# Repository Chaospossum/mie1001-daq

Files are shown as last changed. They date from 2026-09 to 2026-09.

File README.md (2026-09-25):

# MIE1001 Team 5&4 — data acquisition for the portable quadrupole mass spectrometer

Foundation of Imaging Engineering (MIE1001), Maastricht University, 2026.
Team 5 owns the data chain: detector signal → preamp → ADC → Arduino UNO → laptop, plus the DAC that
sends the mass command to the Extrel 150-QC quadrupole controller.

```
Faraday cup ─► preamp (LMP7721, 100 MΩ) ─► ADS1115 16-bit ADC ─I²C─► Arduino UNO ─USB─► laptop
                                               MCP4725 12-bit DAC ◄─I²C─┘ ─► mass command (0-5 V now; Extrel wants 0-10 V)
```

## Contents

| Folder | What |
|---|---|
| `firmware/` | Arduino sketches (open in the Arduino IDE; board: Arduino Uno) |
| `hardware/mie1001_daq_simple/` | **Simple shield, rev E**: plug-in ADS1115 + MCP4725 breakouts, screw terminals, and the Faraday-cup preamp. Ordered from Digi-Key and hand-soldered. See its README |
| `hardware/mie1001_daq_board/` | **Full shield, rev E**: everything soldered (ADS1115, MCP4725, preamp), BNC input, CEM/Faraday ranges |
| `hardware/enclosure/` | First idea for a 3D-printed enclosure (transparent PETG, OpenSCAD source, STLs, renders). Not printed, not a team decision yet |
| `wokwi/` | Wokwi simulation of the whole loop: Uno → MCP4725 → quadrupole stand-in → ADS1115, with custom chips written in C and a PEG1000 test spectrum |
| `data/` | Real measurements (`2026-09-20_selftest/`: first self-tests of the ADS1115 and MCP4725 on the Uno, with plots) and clearly labelled simulations (`simulations/`) |

### Firmware

| Sketch | Tests | For | Serial |
|---|---|---|---|
| `DAQ_shield_scan` | **Mass scan**: DAC code sweep on QPS OUT, preamp current (A1−A3) with 50 Hz window averaging, A2 command read-back (JP1), zero/offset, trigger on D8, self-check (`i`) | **shield** (rev E) | 115200 |
| `DAQ_loopback_test` | DAC → ADC loopback (wire QPS OUT to SIGNAL IN) | **shield** | 115200 |
| `DAQ_mini_chain` | Chain: DAC → UNO A0 → PWM D9 → RC filter → ADS1115. Assumes ADS A1 = DAC; on the shield A1 is PRE_OUT | **breadboard only** | 115200 |
| `ADS1115_selftest` | ADS1115 alone: reads the UNO's 3.3 V, GND and 5 V pins | breadboard | 9600 |
| `MCP4725_standalone_test` | MCP4725 alone, read back on the UNO's A0; scans the I²C bus if not found | breadboard | 9600 |
| `MCP4725_sine_scope` | MCP4725 sine wave, sent vs. read on the Serial Plotter | breadboard | 115200 |
| `SparkFun_MCP4725_waveform` | SparkFun's 512-point sine example (J. Bartlett, 2014, beerware). Its A2/A3 power trick is for a bare breakout on the UNO header, not the shield | breadboard (shield: drop the A2/A3 lines) | — |
| `ioannis_DAC_3V` | Ioannis's sketch: holds the MCP4725 (0x60) at 3 V. Now measures the real 5 V rail first (internal bandgap), since a fixed code 2457 gave ~2.9 V on USB | either | 115200 |
| `PwmGenerator` | Two-channel PWM generator on pins 9/10 (bench tool, not DAQ) | bench | 115200 |

Libraries: Adafruit ADS1X15, Adafruit MCP4725. I²C addresses: ADS1115 0x48, MCP4725 0x60.

### Hardware

Both boards are **generated by Python** (`generate_schematic.py`, `generate_pcb.py`); `./build.sh` rebuilds the
KiCad files, runs ERC, DRC (with schematic parity) and the preamp guard check, and writes the fab files in
`fab/` (gerbers, Digi-Key BOM; the JLCPCB files are optional leftovers). Edits made in the KiCad GUI are overwritten by the next build. Needs KiCad 10 (flatpak `org.kicad.KiCad`).
The simple board's PCB script reuses the router in `../mie1001_daq_board/`, so keep both folders side by side.

## Status (2026-09-25)

- Firmware: all sketches compile for the UNO. The self-tests pass on the real Uno (see `data/`);
  `DAQ_shield_scan` is untested until the shield is soldered.
- Simple shield rev E: fixes from an independent design review (closed guard ring under the LMP7721, mask-free
  guard, 100k/100k VREF divider, A4/A5 wired, JP1 mass-command read-back). ERC, DRC and guard check clean.
  Not yet ordered. Everything is ordered from Digi-Key and soldered by hand. Do a 1:1 paper print check on a real UNO first.
- Open: the Extrel 150-QC mass command is 0-10 V (a x2 stage with its own supply is still needed) and its
  volts-per-amu scaling is unconfirmed.

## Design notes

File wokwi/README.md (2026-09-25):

# MIE1001 — Team 5 acquisition simulation (Wokwi)

Full acquisition loop simulated in Wokwi:

    Arduino Uno --I2C--> MCP4725 (0x60) --analog--> quad --analog--> ADS1115 (0x48) --I2C--> Arduino Uno

The Uno sets a mass command on the DAC, the quad chip returns the ion
signal at that mass, the ADC reads it back. Sweeping the DAC produces a
mass spectrum.

## Files

| File | What it is |
|---|---|
| `sketch.ino` | Scan program: sweeps the DAC, reads the ADC, prints CSV |
| `diagram.json` | Wiring |
| `libraries.txt` | Adafruit ADS1X15 |
| `mcp4725.chip.c/.json` | 12-bit DAC, I2C 0x60 (Team 4's block) |
| `quad.chip.c/.json` | Quadrupole + detector model |
| `ads1115.chip.c/.json` | 16-bit ADC, I2C 0x48 (Team 5's block) |
| `signal.chip.c/.json` | Standalone free-running signal source (ADC test only) |

## Wiring

I2C bus (shared): Uno A4 = SDA, A5 = SCL. MCP4725 at 0x60, ADS1115 at 0x48.
Power: 5V and GND to both breakouts.
Analog path: MCP4725 OUT -> quad IN, quad OUT -> ADS1115 A0.

## Simulated sample

PEG1000. Peaks every 44 Da (ethylene oxide repeat) under a Gaussian
envelope centred near m/z 1010. Peak n sits at:

    m/z = 44n + 41        n = 10 .. 35

Mass command mapping in `quad.chip.c`: 0-5 V spans 0-2000 m/z, so

    DAC value = (m/z) / 2000 * 4095

## Calibration exercise

1. Run the scan, capture the CSV from the serial monitor.
2. Find peak positions in DAC counts.
3. Assign each to its known m/z using the 44 Da spacing.
4. Least-squares fit m/z = a * DAC + b.
5. Check residuals -- they should be flat, not curved.

## Parameters worth changing

`sketch.ino`
- `DWELL_MS` -- settling time per step. Set to 0 and watch peaks distort.
- `SCAN_STEP` -- 1 for full resolution, 2+ for a faster sweep.
- `AVERAGES` -- reads averaged per step; trades speed for noise.
- `ads.setGain()` -- GAIN_ONE is +/-4.096 V. Higher gain resolves more but clips sooner.

`quad.chip.c`
- `PEAK_SIGMA` -- peak width, i.e. resolution.
- `NOISE` -- baseline noise amplitude.
- `MZ_MAX` -- mass range spanned by the 0-5 V command.

## Limitations

The quad chip is a lookup, not physics. Real quadrupoles have
mass-dependent transmission, resolution set by the DC/RF ratio, and
non-Gaussian peak shapes. This is enough to develop and validate
acquisition software, not to predict instrument performance.

## Notes

- The custom chips (`*.chip.c`) were generated with AI (Claude) and checked by us; see the AI declaration in the report.
- `ADS1115_INPUT/` is a smaller first test: the ADS1115 alone with a signal source.
- To run: create a new Arduino Uno project on wokwi.com and upload these files (the chips need the "custom chip" feature).
- Files recovered from a local backup on 25 September 2026 (originally made 3 September).

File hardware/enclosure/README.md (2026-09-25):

# MIE1001 Team 5 DAQ enclosure

A two-part, support-free enclosure in **transparent (recycled) PETG** for the Arduino UNO R3 (SMD CH340
clone) with the `mie1001_daq_simple` shield (rev D/E) stacked on it. You can see the UNO's LEDs (ON, L, TX,
RX) through the side walls, in the 11 mm gap between the UNO and the shield, and you can see the shield and
both breakouts through the lid.

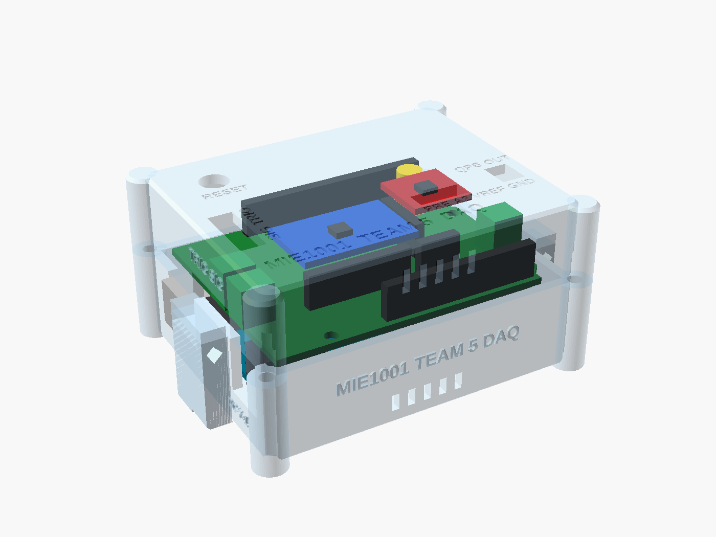
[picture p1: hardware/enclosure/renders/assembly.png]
assembled


| | |
|---|---|
| Outside (walls) | 77.4 × 61.1 × 41.5 mm (lid top 41.5 mm above the table) |
| Outside (incl. corner posts, cable-tie blocks) | 89.4 × 68.3 mm |
| Base / lid as printed | 89.4 × 68.3 × 24.7 mm / 84.6 × 68.3 × 19.5 mm |
| Filament, time (PrusaSlicer 2.9.6, 0.2 mm, 100 %) | base 37.5 g, 5 h 08 · lid 30.2 g, 4 h 02 · **total ≈ 68 g, 9 h 10** |

## Files

| Path | What |
|---|---|
| `scad/daq_enclosure.scad` | **The design.** All dimensions are parameters at the top of the file. `part = "assembly" / "exploded" / "base" / "lid" / "lid_print" / "spacer"` |
| `scad/pcb_positions.scad` | Connector positions, **generated** from the shield's `.kicad_pcb`. Don't edit it by hand |
| `stl/daq_base.stl` | Base tray, printing orientation (floor on the bed) |
| `stl/daq_lid.stl` | Lid, already flipped for printing (top face on the bed) |
| `stl/daq_spacer_x2.stl` | 2 spacers (Ø5.6 × 10.8 mm) between the UNO and the shield at holes H2/H3 |
| `print/petg_clear_0.2mm.ini` | PrusaSlicer settings (print + filament; the printer part is generic) |
| `renders/*.png` | assembly, assembly_back, exploded, boards_only, base, base_left, lid_top, lid_print |
| `build/fit_table.md` | Clearance table (generated by `tools/fit_check.py`) |
| `tools/dump_pcb.py`, `tools/make_positions.py` | KiCad board → JSON → `pcb_positions.scad`. They only read the board, from a snapshot copy |
| `build.sh` | Rebuilds everything: `./build.sh` (or `--no-pcb`, `--no-slice`) |

Tools: the OpenSCAD 2026.09.23 AppImage from files.openscad.org is in `~/Applications`. To edit, open the
`.scad` in OpenSCAD, change a parameter, press F5 (preview) or F6 (render), then **File › Export › STL**. Or run
`./build.sh`. PrusaSlicer is the flatpak `com.prusa3d.PrusaSlicer`. Its CLI runs without a display.

## How it goes together

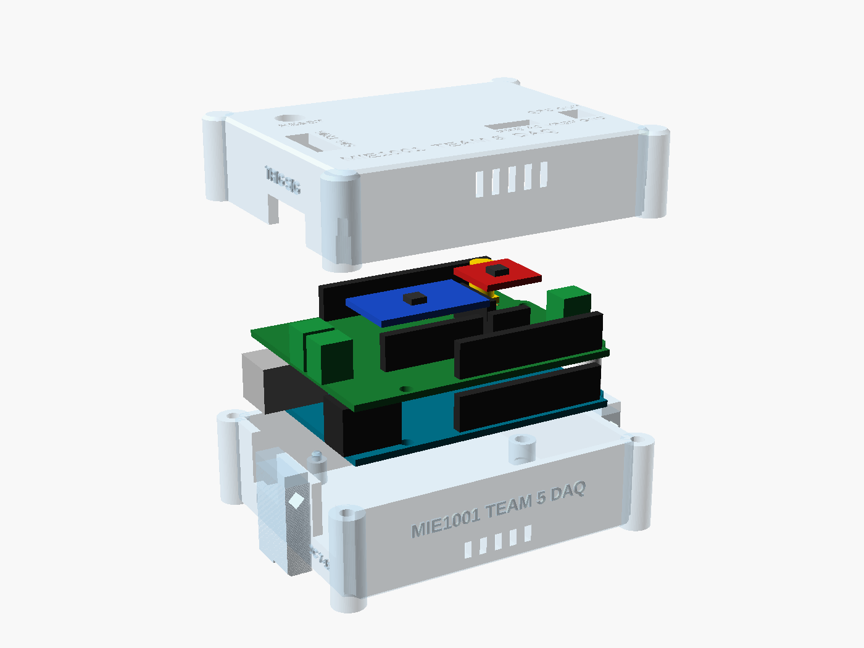
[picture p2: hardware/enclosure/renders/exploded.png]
exploded


- **Coordinates:** the origin is the UNO's lower-left corner, seen from the top as on the A000066 drawing.
  USB-B and DC are on the left, the power header is at the front, and the digital header is at the back.
  The parting plane is at z = 22.0, which is 1 mm above both jacks.
- **Base:** it has a 2.4 mm floor and 2.4 mm walls. The UNO sits 6 mm above the floor on 4 supports:
  - At **H2 (66.04, 7.62) and H3 (66.04, 35.56)**: Ø7 bosses with **M3 heat-set inserts** (M3 × 5.7, 4.0 mm hole).
  - At **(13.97, 2.54)** and **(15.24, 50.8)**: support pins with a locating peg. No screw goes there. An M3 head
    or spacer at the first would hit the DC-jack body (the A000066 drawing shows the hole partly under it), and at
    the second it would hit the SCL header pin.
  - The USB-B and DC jacks sit in **U-notches that are open at the top**, so the finished stack drops straight in.
    The lid wall closes them 1 mm above the jacks.
  - Low vent slots are in the front and back walls, and recesses on the underside take 4 × Ø10 mm rubber
    bumpers (the feet).
- **Stack:** two printed spacers go at H2/H3 between the UNO and the shield. Fix each with an **M3 × 20** screw
  from the shield top through the spacer and the UNO into the insert, so both boards are clamped. The shield's
  H1 gets no screw.
- **Lid:** fastened by 4 × **M3 × 30 countersunk** screws (ISO 10642). They go in **from underneath** through the
  corner posts of the base, into heat-set inserts in the lid posts, so the top stays clean and clear.
- **Wires J1 SIGNAL IN / J3 TRIG** (left) and **J2 QPS OUT** (right) leave through slots at the bottom edge of the lid
  wall, at the height of the terminal entries. Under each slot, a block on the outside of the base has a
  diamond-shaped tunnel for a **cable tie (≤ 4.8 mm)**. Lay the wires on the block and tie them down; this is the
  strain relief. Tighten the terminal screws from above through the **screwdriver windows** in the lid
  (2.5–3 mm blade).
- **J4** (PRE_OUT, A2, VREF, GND): a 12 × 4.5 mm slot above the socket takes 4 Dupont jumpers from above.
- **J5 Faraday cup:** `faraday_mode = "none"` (default, team choice 25 Sept) makes a plain box for the UNO and
  shield only: no opening for the detector, and the SMA jack stays under the lid. `faraday_mode = "passthrough"` gives a Ø12.5 hole, so the SMA-male → BNC-female
  adapter screwed onto J5 sticks up through the lid (not the default any more). Two slots next to the hole let you **cable-tie the BNC cable
  to the lid**, so a pull on the cable doesn't twist the SMA jack off the shield. `faraday_mode = "bulkhead"`
  gives a 9.7 mm D-hole (8.9 mm flat) for a BNC bulkhead jack in the lid, with a short SMA-male pigtail inside.
  That is more robust mechanically, but the extra cable adds capacitance and triboelectric noise at pA levels,
  so the direct adapter is the better choice electrically. Check the hole against your bulkhead's datasheet.
- **Reset:** the UNO's button is **under the shield** (true of every shield), so no hole can reach it. The lid has an
  optional Ø7 hole (`reset_button = true`) for a 6–7 mm panel push button (normally open). Wire it with two short
  wires to the **RESET** and **GND** legs of the stacking header between the boards. Without the button, opening
  the serial monitor or uploading resets the board anyway (DTR auto-reset of the CH340).
- **Labels:** raised on the walls (SIG, TRIG, QPS OUT, USB, DC 7-12V, MIE1001 TEAM 5 DAQ). On the lid top they are
  **engraved** (MIE1001 TEAM 5 DAQ, FARADAY CUP, SMA > BNC, PRE A2 VREF GND, QPS OUT, SIG, TRIG, RESET). The top is
  printed face-down, so raised text there would need supports.

Assembly order:
1. Press the inserts in with a soldering iron at ~230 °C.
2. Plug the shield onto the UNO with the spacers, then fit the 2 × M3 × 20 screws.
3. Drop the stack into the base.
4. Screw the SMA→BNC adapter onto J5 finger-tight, and wire the terminals.
5. Lower the lid over the adapter and fit the 4 × M3 × 30 screws from below.
6. Tie the cables down.

## Shielding: transparent PETG gives **zero** EMI shielding

The picoamp preamp (U3 LMP7721, R6 100 MΩ, the J5 input, all inside the VREF guard) picks up mains hum and
anything that moves nearby. Nothing of the enclosure comes within 16.5 mm of it, and no rib or post touches the
shield. If the zero reading is noisy with the beam off:

- Stick **copper tape (or aluminium foil tape with conductive adhesive) inside the lid ceiling, only over the
  preamp.** An engraved 0.4 mm outline on the underside of the lid top marks the patch: board x 26–63, y 36.5–52,
  about 37 × 15 mm. Cut the Ø12.5 hole out of it. The rest of the lid stays clear.
- **Ground it.** Let the tape touch the SMA adapter's body (its shell is GND through J5), or solder a thin wire from
  the tape to J4 pin 4 (GND). A floating patch can make the noise worse.
- The patch is removable: peel it off for demos.
- A patch on the lid only shields from above. For a full cage, add a second patch on the floor under the UNO,
  grounded to the same point, or wrap the whole unit in foil during measurements.

## Printing (transparent PETG, 0.4 mm nozzle)

| Setting | Value | Why |
|---|---|---|
| Orientation | base: floor down · lid: top face down (the STL is already flipped) | the smooth bed face is the clearest face |
| Supports | **none** | notches open at the parting plane, 45° countersinks, a diamond cable-tie tunnel, and vertical slots ≤ 1.8 mm wide |
| Layer height | 0.2 mm (first 0.2 mm) | |
| Walls | 6 perimeters (= the 2.4 mm walls) | a solid wall has no infill pattern showing through |
| Top/bottom | 12 solid layers (= the 2.4 mm floor and top) | |
| Infill | **100 %**, rectilinear/monotonic, lines aligned | the other way to get clarity is **0 % infill with enough perimeters/solid layers to fill everything**. Anything in between (gyroid, 20 %) looks milky |
| Extrusion | 1.03 flow, 0.45 mm width | slight over-extrusion squeezes out the air gaps between lines. Air gaps make a part cloudy |
| Temperature | 245 °C first layer, **250 °C** after (the top of the PETG range) | hotter = better fusion = clearer |
| Speeds | outer walls **15 mm/s**, inner walls 25, solid infill 30 | slow and steady = fewer bubbles |
| Fan | 15–30 % (off for 3 layers) | a strong fan freezes the lines apart |
| Bed | 80 °C, smooth PEI or glass | a textured sheet gives a frosted bottom face |
| Ironing | **off** | on PETG it smears and fogs the top |
| Filament | **dry it** (65 °C, 4–6 h). rPETG works the same way | wet PETG pops and makes bubbles |

The finished parts are "clear", not glass-like; slicing lines always show a little. For the lid top, the bed face
is the best face. If you want it clearer still, wet-sand with 800 → 2000 grit and polish, or wipe on a thin coat
of clear lacquer.

Hardware:
- 6 × M3 heat-set inserts (M3 × 5.7, Ø4.0 hole)
- 2 × M3 × 20 screws (for the stack)
- 4 × M3 × 30 countersunk screws (for the lid)
- 4 × Ø10 × 1 mm rubber bumpers
- cable ties ≤ 4.8 mm
- optional: a 6–7 mm panel push button
- optional: copper tape

## Fit check (`python3 tools/fit_check.py` → `build/fit_table.md`)

The shield positions come from the `.kicad_pcb` (snapshot of 2026-09-25, rev D/E, connectors frozen). The UNO
jacks come from the A000066 outline drawing. Every clearance is ≥ 1 mm except the one marked `tight`.

| Opening | Enclosure | Part | Clearance mm |
|---|---|---|---|
| USB-B notch, sides / bottom / top | y 31.1–45.1, z 9.0–22.0 | jack y 32.1–44.1, z 10.0–21.0 | 1.0 / 1.0 / 1.0 |
| USB-B reach | outer wall x −4.4 | jack front x −6.5 | sticks out 2.1: the plug mates fully |
| DC notch, sides / bottom / top | y 1.2–12.8, z 9.0–22.0 | jack y 2.4–11.6, z 10.0–21.0 | 1.2 / 1.0 / 1.0 |
| DC plug reach | outer wall x −4.4 | jack front x −1.6 | recessed 2.8: the plug body must be ≤ 11.6 mm across |
| J1 SIGNAL IN wire slot (left) | y 12.3–30.8, z 22.0–29.0 | entries y 15.4 / 18.9, z 26.5 | 1.6 (3 mm wire) / 1.0 |
| J3 TRIG wire slot (same slot) | " | entries y 24.2 / 27.7 | 1.6 / 1.0 |
| J2 QPS OUT wire slot (right) | y 11.4–21.1, z 22.0–29.0 | entries y 14.5 / 18.0 | 1.6 / 1.0 |
| J1/J3/J2 body vs lid wall | x −2.0 / 70.58 | body x −0.91 / 69.48 | 1.1 |
| Screw windows J1+J3 / J2 | 5.8 × 16.3 / 5.9 × 7.5 mm | 3 mm blade | ≥ 1.0 (7.3 mm deep) |
| J4 Dupont slot | x 41.7–53.8, y 12.3–16.8 | socket x 42.7–52.8, y 13.3–15.8 | 1.0 |
| J5 adapter hole Ø12.5 at (58.34, 43.54) | | SMA nut 9.2 across corners / BNC studs 11.6 | 1.65 / 0.45 (pass-through only) |
| Lid ceiling z 39.1 | | breakouts z 37.1 / headers z 31.1 | 2.0 / 8.0 |
| Boards vs walls | | x / y | 2.0 / 1.5 |
| Lid posts vs board corners | r 4.0 | | 1.3 |
| Bosses/pegs vs shield H1–H3 | | | 0.00 position error |
| H3 spacer vs UNO ICSP header | Ø5.6 | keep-out y ≤ 32.14 | **0.6 (tight)** to the keep-out, ~1 mm to the header |
| Preamp guard | | | nothing within 16.5 mm above, 6.7 mm to the back wall |

## Assumptions and open questions (measure your boards!)

1. **Jack heights on the clone** (`jack_h` = 11.0) and the **stack gap** (`stack_gap` = 11.0, the shield resting
   on the USB-B shell). Measure the UNO top → USB shell top, and the UNO top → shield underside, with the real
   stacking headers. `z_split` follows `jack_h` automatically.
2. **Jack positions on the clone:** USB y 38.1, 12.0 wide, sticks out 6.5 mm; DC y 7.0, 9.2 wide, sticks out
   1.6 mm, axis 6.4 mm above the UNO. These were scaled from the A000066 drawing, and clones can differ by
   ±0.5 mm. Set `usb_*` / `dc_*`.
3. **Parts under the UNO** near the two support pins (DC-jack solder tails next to (13.97, 2.54)). The pin boss is
   Ø5; make `peg_boss_d` smaller if it hits.
4. **Breakout height** `brk_h` = 14.5: 8.5 socket + 2.5 pin spacer + 1.6 PCB + parts. Both breakouts **lie flat**
   (component side up) on their pin headers (README of the shield, silkscreen outlines). If your header
   is longer, raise `brk_h`.
5. **Phoenix PT 1,5/2-3,5-H:** body height 9.2 (KiCad 3D model). The wire entry at 3.9 mm above the PCB and the
   screw position are assumed; the window covers the whole front of the block.
6. **SMA height** (`sma_h` = 10.2, Amphenol 132134) and the length of your SMA→BNC adapter. In
   passthrough mode the adapter must reach at least 17 mm above the shield. If a bulkhead is used, check the
   D-hole.
7. **J4 is 1 × 4** on the PCB (PRE_OUT, A2, VREF, GND), not 1 × 3 as in the brief. The slot fits 4 pins.
8. The UNO's LEDs are under the shield: see them from the side through the base walls, not from the top.
9. Print one test piece first: `part="base"` cropped to the left wall (jacks), or simply the spacers + a wall
   section. PETG shrink is small, but the 0.3 mm fits depend on your printer.

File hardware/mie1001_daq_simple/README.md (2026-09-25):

# MIE1001 — simple DAQ shield (rev E)

The beginner version of the DAQ board: an Arduino UNO R3 shield that the two breakout
boards from class plug into (modular: both unplug). Fat tracks, the breakouts, connectors and
through-hole parts are hand-soldered. **Rev D adds a Faraday-cup preamp** with 16 small SMD parts.
**Everything is ordered from Digi-Key** (university procurement, see [Ordering from Digi-Key](#ordering-from-digi-key))
**and hand-soldered** (see [Hand-soldering order](#hand-soldering-order)); JLCPCB assembly is an optional alternative.

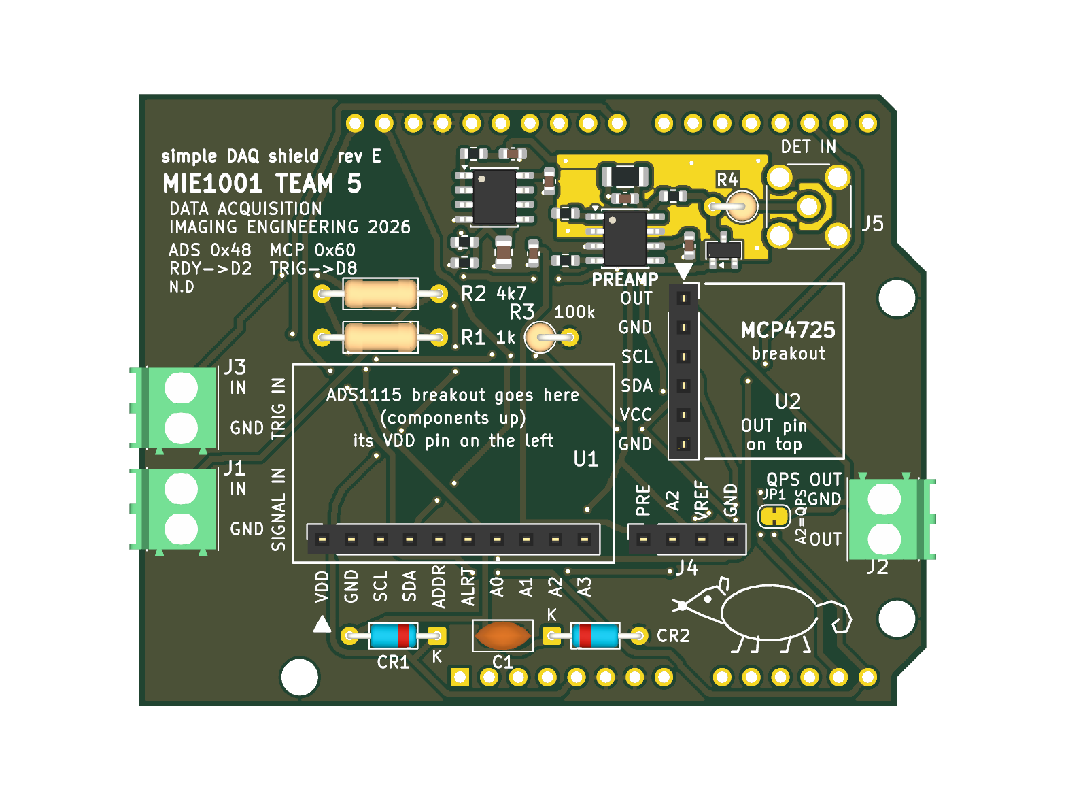
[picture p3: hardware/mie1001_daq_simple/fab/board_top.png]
board, top

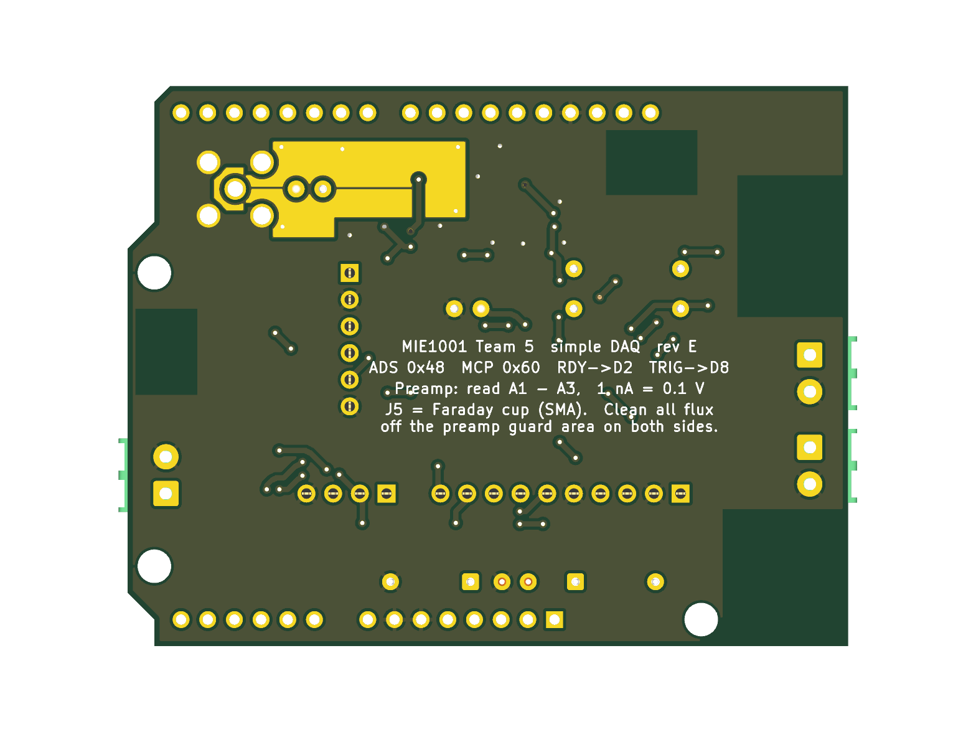
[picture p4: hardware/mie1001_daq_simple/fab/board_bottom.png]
board, bottom


```
SIGNAL IN (J1) -> R2 4k7 -> [CR1/CR2 clamp, C1 filter] -> ADS1115 breakout A0 -> I2C -> UNO -> USB -> laptop
UNO -> I2C -> SparkFun MCP4725 breakout OUT -> QPS OUT (J2), 0-5 V  (JP1, bridged: also -> ADS1115 A2 read-back)
TRIG IN (J3) -> R1 1k -> UNO D8 (R3 100k to GND)    ADS1115 ALRT -> UNO D2
Faraday cup -> J5 SMA -> R4 10k -> CR3 clamp to VREF -> R5 1k -> U3 LMP7721 preamp (R6 100M || C2 10p)
            -> R11/C6 1k/1u -> ADS1115 A1 (PRE_OUT)      VREF 2.5 V (R8/R9 100k/100k + C4 -> U4A MCP6002 -> R10 -> C5) -> A3
J4 = test header: 1 PRE_OUT, 2 A2 (QPS read-back while JP1 is bridged), 3 VREF, 4 GND
I2C: UNO SDA/SCL header pins AND A4/A5 (rev E)
```

| Check | Result |
|---|---|
| ERC | 0 errors, 0 warnings |
| Guard check (`check_guard.py`, rev E) | PASS: 0 items of any other net within 1.0 mm of the preamp input (COAX_IN, DET_IN, TIA_IN, TIA_REF), every input item has guard copper within 0.6 mm, and the bare-board flood fill from the input reaches only VREF and TIA_OUT on F.Cu and only VREF on B.Cu. The same script FAILS on the rev D board (7 leakage paths), so it catches the rev D defect |
| Independent critical review | Two reviews against the Adafruit, SparkFun, Arduino, Phoenix and TI source files and datasheets. Rev A: pinouts and UNO geometry correct, four fixes → rev B. Rev C: copper clean, no respin needed; one wrong BOM part number and several wrong claims in this file, all corrected below |
| Host board | Arduino UNO R3 **SMD** (ATmega328P in a flat TQFP-32 package). Its headers are identical to the standard R3 (same positions, same pins, SDA/SCL next to AREF), so the shield fits unchanged |
| Still unverified | The height of the parts on the UNO under the shield (crystal, USB chip, capacitors). The SMD chip itself is only about 1.2 mm tall, so this is much less of a risk than with the socketed DIP chip, but look at your board before soldering |
| DRC incl. schematic parity | 0 errors, 0 unconnected, 0 parity issues (4 `lib_footprint_mismatch` warnings: ARD1 and J1–J3 are deliberately modified copies) — rev E |
| Orientation | Same real-UNO geometry as the full board (rev E): flipped library footprint, keep-outs over the USB, DC jack and both ICSP headers |
| Rules | 0.5 mm tracks, ≥ 0.3 mm gaps, 0.8/0.4 mm vias: far above the Digi-Key PCB Builder (5 mil / 8 mil) and JLCPCB minimums |

## What changed in rev E (2026-09-25)

An independent review of rev D found a leakage path and a few smaller problems. **No connector,
socket or mounting hole moved** (J1–J5, the two breakout sockets, H1–H3 are where they were in rev D).
The router re-laid most of the signal tracks because the obstacles changed; that does not matter
electrically, DRC and the guard check are clean.

- **Guard closed under U3.** In rev D the guard pour stopped halfway under the LMP7721, and TIA_OUT
  ran from the feedback parts under the chip body to pin 4. The copper-free gap alongside it was a
  bare-board path from the input to GND (pin 3) and +5V (pin 6). Now a VREF bar runs under the
  chip from pin 2 to pin 7 (both N/C pins, on the guard), so the input pins 1 and 8 sit in a closed
  guard pocket, and TIA_OUT leaves the guard on the **bottom layer only**: via next to R6/C2, under
  the chip, via below the bar, then to pin 4 and R11. On the top layer the input is now completely
  surrounded by guard copper; the only other net it faces is TIA_OUT across C2 and R6 themselves,
  which only adds in parallel with the feedback resistor (TI LMP7721 datasheet, 10.1).
  DET_IN was re-laid as two straight runs so the guard hugs it everywhere.
- **No solder mask on the guard (both layers).** The mask openings are the guard pour shrunk by
  0.10 mm and kept ≥ 0.50 mm from any pad and ≥ 0.40 mm from any track of another net, and off all
  silkscreen. So every other track, every gap next to the guard and the edge of the GND pour stay
  under mask: exposed guard copper is never closer than 0.4 mm (mask web) to exposed copper of
  another net, which keeps solder bridges unlikely. Care points: the SMA J5 ground pins sit next to
  the bare guard ring around the centre pin (≥ 0.5 mm mask web); don't flood them with solder, and
  check there is no bridge from a J5 ground pin to the ring before powering up.
- **`check_guard.py` is strict now.** It fails (exit 1) on any unguarded input item (it used to only
  print them) and adds a bare-board flood fill from the input nets on each copper layer: reaching
  copper of any net other than VREF / TIA_OUT, or leaving the guard area, fails the build.
  `check_guard.py .history/revD-final/mie1001_daq_simple.kicad_pcb` shows the rev D failure.
- **Quieter VREF.** R8/R9 are now 100k/100k (were 10k/10k). With C4 10 µF the divider's corner is
  0.32 Hz instead of 3.2 Hz, so 50 Hz ripple on the USB 5 V reaches VREF attenuated ~160× instead
  of ~16×. The MCP6002's ~1 pA input bias current makes no measurable error through 50k.
- **A4/A5 also carry SDA/SCL.** On a genuine UNO R3 they are the same signals as the SDA/SCL pins
  next to AREF; some clones don't have those two pins, and then the shield works through A4/A5.
  Consequence: **never use A4/A5 as analog inputs** with this shield fitted.
- **JP1, QPS read-back.** A solder jumper, bridged by a copper strip from the factory, connects
  QPS OUT (MCP4725 OUT, J2) to ADS1115 **A2** (J4 pin 2). The firmware can read the command voltage
  it actually set: `ads.readADC_SingleEnded(2)`, with the ±6.144 V range
  (`ads.setGain(GAIN_TWOTHIRDS)`), because 0–5 V does not fit the ±4.096 V range. To use A2 for something else, cut the thin copper
  bridge between JP1's pads with a knife (check with a meter); a blob of solder closes it again.
  JP1 is next to J4, marked "JP1 / A2=QPS".
- **C5/C6 part (optional JLC route only).** LCSC C15849 had no LCSC stock; now C5673 (Samsung CL10A105KA8NNNC, 1 µF 25 V X5R
  0603, extended part: one extra JLC loading fee). There is no other *basic* 1 µF 0603 at JLC;
  JLC's own library still listed C15849 in stock on 2026-09-25, so it is a valid fallback.
- **Docs:** J4 firmware note rewritten (pins 1 and 3 are op-amp outputs), wrong 8 SPS/mains claim
  corrected, comparison with the full board corrected, U3 "no solder mask" note is now true.

## What changed in rev D (2026-09-24): the preamp

The Faraday cup gives a current of pA to nA. The ADS1115 measures voltage, so rev D adds a
**transimpedance amplifier** (U3, LMP7721) that turns 1 nA into 0.1 V. Everything that was on rev C
stays where it was; the preamp sits in the band under the digital header, where the text used to be
(the text moved to the left edge and the back).

| Part | Job |
|---|---|
| **J5** SMA jack (vertical, PTFE) | Detector input. Use a **BNC-female to SMA-male adapter** for a BNC cable. A BNC did not fit anywhere on this board |
| **U3** LMP7721 + **R6** 100 MΩ | The preamp: Vout = VREF − I × 100 MΩ. Full scale ~25 nA; 1 ADC count = 1.25 pA at GAIN_ONE |
| **C2** 10 pF | Stops the preamp oscillating with the cable capacitance. Sets a 159 Hz bandwidth |
| **R4** 10k + **CR3** BAV199 + **R5** 1k | Protect U3 from a discharge on the cable. CR3 is tied to VREF, so it leaks ~0 into the input |
| **VREF** 2.5 V: R8/R9 100k/100k (rev E), C4 10 µF, U4A MCP6002, R10 100 Ω, C5 1 µF | The input sits at 2.5 V so the output can swing both ways on a single 5 V supply |
| **R7** 1k | Protects U3's + input |
| **R11** 1k + **C6** 1 µF | 159 Hz anti-alias filter before ADS1115 **A1** |
| **Guard ring** (copper at VREF, both layers, no solder mask) | Surrounds the whole input so no other copper can leak pA into it; closed under U3 between pins 2 and 7 (rev E) |

**Firmware:** read the preamp as `ads.readADC_Differential_1_3()` (A1 − A3 = PRE_OUT − VREF), then
`I = −V / 100e6`. The ADS1115 only offers the pairs 0-1, 0-3, 1-3 and 2-3, which is why VREF is on A3.
SIGNAL IN (J1) → A0 still works as before for a voltage input.

**J4 changed:** pin 1 is now PRE_OUT and pin 3 is VREF (monitor only: connect a meter or scope, never a
source). Pin 2 (A2) carries the QPS read-back while JP1 is bridged (rev E); cut JP1 to use it as a free input.

**Still 0-5 V on QPS OUT.** The Extrel 150-QC wants a 0-10 V mass command; that needs a gain-2 amplifier on
a supply above 10 V (e.g. a 12 V adapter on the UNO's DC jack). Not on this revision.

**Handling:** the input works at picoamps. After soldering, wash off **all** flux around U3, R6, C2, R4 and
J5 (isopropyl alcohol, then dry), handle the board by its edges, and measure the zero offset with the
cable connected and the beam off before every scan.

## Names on the drawing and the board (2026-09-24, copper unchanged)

- The UNO is **ARD1** and the clamp diodes are **CR1, CR2** (were A1, D1, D2), so the names no longer clash
  with the UNO's pins A1 and D2.
- The UNO symbol shows only the pin names printed on the UNO (D2, D8, SDA ...), not KiCad pad numbers.
- SDA/A4 and SCL/A5 are the same signals on the UNO R3. Since rev E the shield connects A4/A5 as well
  (for clones without the SDA/SCL pins), so never use A4 and A5 as analog inputs.

## What changed in rev C

Three parts on the signal input, in the free band under the ADS1115 socket:

- **C1 (100 nF) to ground.** With R2 it is a single-pole low-pass at **339 Hz**, and it supplies the
  charge the ADC's switched-capacitor input takes at each sample. It takes the edge off fast noise
  and limits the bandwidth, so leave it out if you need to measure something faster than ~300 Hz.
  **It does not remove mains hum**: at 50 Hz it attenuates by only 1.1 %. See the firmware notes for
  what actually works. **C1 must be X7R or C0G, not Y5V** (a Y5V part loses most of its value when
  warm, which moves the corner frequency anywhere up to ~2 kHz).
- **CR1 and CR2 (1N4148) clamps.** They divert most of an over-voltage to the rails. Be clear about
  what does the work: **R2 is what keeps the chip legal** (1.3–2.4 mA at ±12 V against its 10 mA
  limit), because the 1N4148 only starts conducting around 0.5–0.7 V, by which point the input is
  already past the ADC's absolute maximum of VDD + 0.3 V and the chip's own internal protection
  diode is conducting alongside CR1. The diodes are there for the energy of a static zap or a badly
  wrong connection, not to hold the pin inside spec. TI also warns that overdriving one input can
  upset conversions on the others: **while A0 is overdriven, readings on A1–A3 are not valid either.**
- **What the diodes cost:** up to 25 nA of leakage each, which through R2 is up to 117 µV of offset
  (15 counts at GAIN_SIXTEEN, and several times worse when hot). Fine at low gain; calibrate the
  offset if you use the high gain ranges.
- **One side effect:** with the Uno unpowered, a signal above 5 V feeds up to 2.4 mA (at +12 V) back into its
  5 V rail through CR1. Don't leave a live preamp connected to an unpowered board.
- **No amplifier.** The ADS1115 has a programmable gain amplifier built in, so a small signal is
  handled in software with `ads.setGain(...)` instead of another chip. Note that at the highest
  gains the chip's differential input resistance falls to about 710 k, where R2 costs ~0.66 % of
  gain (under 0.1 % at the ±6.144 V range, 0.2–0.4 % at ±2.048 and ±1.024 V): calibrate if you use GAIN_SIXTEEN. Note TI suggests keeping
  a filter resistor under 1 k; 4.7 k is deliberate here, chosen for protection, and C1 at the pin
  supplies the sampling charge that the series resistance otherwise would.

**Watch the stripe when soldering the diodes.** The silkscreen prints **K** at the cathode end of
each one, and that is the end with the black band on the part. CR1's K points right, towards +5 V.
CR2's K points left, towards the signal. Backwards, they short the signal to a rail.

## What changed in rev B

- **R2 (4k7) in series with SIGNAL IN.** The ADS1115 input may not go above VDD + 0.3 V (TI
  datasheet, absolute maximum ratings). If the preamp swings to its ±12 V rails, R2 keeps the current
  into the chip's input clamp to 1.3–2.4 mA (its limit is 10 mA). Gain error: under 0.1 % on the ±6.144 V
  range, 0.66 % on the ±0.256 V range.
- **R3 (100k) pull-down on D8.** A TRIG IN with nothing connected now reads LOW instead of
  picking up noise and giving false triggers.
- **Pin-1 triangles and "which way round" text on both sockets.** Both breakouts fit in their
  sockets rotated 180°. For the MCP4725 that puts 5 V on its GND pin. Now the MCP4725 outline is
  the real 15.2 × 15.2 mm board.
- **Firmware and BOM fixes.** `dac.begin(0x60)` (the library default is 0x62), and the BOM no
  longer orders the new two-row ADS1115 board that doesn't fit.

## Before you order: three things to check by hand

1. **Which ADS1115 board do you have?** Use the one from the class kit; do not order a new one. This shield fits the **original** Adafruit board with
   **one row of 10 pins** (VDD GND SCL SDA ADDR ALRT A0 A1 A2 A3). Adafruit now sells a newer
   STEMMA QT version (two rows of 6, "VIN" instead of "VDD") under the same product number
   1085, and **it does not fit**. Your team's self-test sketch says "VDD", so you probably have
   the original, but count the pins.
2. **Print `fab/print_1to1_top.pdf` at 100 %** and lay the UNO and both breakouts on it. The
   header holes must line up with the UNO's pins and with each breakout's pins.
3. **Height over the UNO's chip area.** CR1, CR2, C1, the ADS1115 socket and J4 all sit above it.
   On the UNO R3 SMD the ATmega328P is a flat TQFP (about 1.2 mm), so the chip itself is no problem;
   check that nothing else on your board (crystal, USB chip, capacitors) is taller than the gap, and
   trim the leads flush.

## Parts (full list in `BOM.csv`)

| Ref | Part | Where |
|---|---|---|
| U1 | Adafruit ADS1115 breakout (original, 1×10), **from the class kit** | plugs into a 1×10 female header (Sullins PPTC101LFBN-RC, Digi-Key S7008-ND). Don't order 1528-1085-ND: that is the new two-row board |
| U2 | SparkFun MCP4725 breakout BOB-12918 | plugs into a 1×6 female header (PPTC061LFBN-RC, S7004-ND). Retired at SparkFun, still Active at Digi-Key 1568-12918-ND (656 in stock on 2026-09-25). If it is gone, use the class-kit board: Adafruit's MCP4725 breakout is **not** pin-compatible (VIN/GND/SCL/SDA/A0/VOUT, no second GND) |
| J1, J2, J3 | Phoenix 1984617 screw terminals, 3.5 mm | Digi-Key 277-1721-ND |
| J4 | 1×4 female header for the spare inputs | S7002-ND |
| R1 | 1k ¼ W resistor on the trigger | 1.0KQBK-ND |
| R2 | 4k7 ¼ W resistor in series with SIGNAL IN | 13-CFR-25JB-52-4K7-ND |
| R3 | 100k ¼ W pull-down on D8, mounted standing up | 13-CFR-25JB-52-100K-ND |
| C1 | 100 nF 50 V **X7R** disc, **2.5 mm lead pitch** (not Y5V: BC1160-ND is the wrong one) | BC1084CT-ND |
| CR1, CR2 | 1N4148 signal diodes (DO-35) | 1N4148FS-ND |
| — | UNO stacking headers (1×10, 2× 1×8, 1×6, 10.5 mm legs) | Adafruit 85, Digi-Key **1528-1074-ND** (legs just clear the USB jack) |
| U3, U4, CR3, R5–R11, C2–C7, J5, R4 | the preamp | all Digi-Key, see `BOM.csv` / `fab/digikey_bom.csv` |

No other parts. Both breakouts already carry the I²C pull-ups: the ADS1115 board has 10k on
SDA and on SCL (hard-wired), the MCP4725 board has 4.7k on each through jumper SJ1 (closed by a
trace from the factory). In parallel that is 3.2k per line, about 2.9k once the Arduino's own
internal pull-ups are counted, which draws 1.6 mA at the low level against the 3 mA an I²C
device must sink. The minimum sensible value here is about 1.5k, so this is fine and the shield
adds no pull-ups of its own. If you ever chain more I²C boards onto this one, each brings its own
pull-ups and the total drops: cut SJ1 on the MCP4725 board to take its 4.7k pair off the bus.
The ADS1115 breakout also pulls ALRT (UNO pin D2) up with 10k.

## Ordering from Digi-Key

Everything is bought from Digi-Key (university procurement). Checked on digikey.com on **2026-09-25**:
every part number below exists, matches the MPN and package in `BOM.csv`, is **Active** and is in stock.

### Parts: `fab/digikey_bom.csv`

`./build.sh` writes `fab/digikey_bom.csv` in Digi-Key's **BOM Manager / "Upload a list"** format
(`Digi-Key Part Number, Manufacturer Part Number, Manufacturer, Quantity, Customer Reference`), 24 lines,
**quantities for ONE board**. Not in it (do not order): the UNO (ARD1) and the ADS1115 breakout (U1),
both from the class kit. Upload it, then set the quantities you want (below).

| Ref | Digi-Key P/N | MPN | Stock 2026-09-25 | Unit price (USD, qty for 1 board) |
|---|---|---|---|---|
| C1 | BC1084CT-ND | Vishay K104K15X7RF5TL2 | 209,208 | 0.29 |
| C2 | 1276-1027-1-ND | Samsung CL10C100JB8NNNC | 289,398 | 0.10 |
| C3, C7 | 732-8013-1-ND | Würth 885012206095 | 508,777 | 0.10 |
| C4 | 587-4334-1-ND | Taiyo Yuden TMK212BBJ106KGHT | 13,242 | 0.29 |
| C5, C6 | 1276-1102-1-ND | Samsung CL10A105KA8NNNC | 734 | 0.10 |
| CR1, CR2 | 1N4148FS-ND | onsemi 1N4148 | 663,443 | 0.10 |
| CR3 | BAV199LT1GOSCT-ND | onsemi BAV199LT1G | 290,353 | 0.16 |
| J1–J3 | 277-1721-ND | Phoenix 1984617 | 44,569 | 0.59 |
| J4 | S7002-ND | Sullins PPTC041LFBN-RC | 46,150 | 0.42 |
| J5 | ACX1230-ND | Amphenol RF 132134 | 23,380 | 9.98 |
| R1 | 1.0KQBK-ND | YAGEO CFR-25JB-52-1K | 200,942 | 0.10 |
| R2 | 13-CFR-25JB-52-4K7-ND | YAGEO CFR-25JB-52-4K7 | 109,075 | 0.10 |
| R3 | 13-CFR-25JB-52-100K-ND | YAGEO CFR-25JB-52-100K | 92,597 | 0.11 |
| R4 | 13-CFR-25JB-52-10K-ND | YAGEO CFR-25JB-52-10K | 148,616 | 0.10 |
| R5, R7, R11 | 311-1.00KHRCT-ND | YAGEO RC0603FR-071KL | 3,768,097 | 0.10 |
| R6 | HVCB1206FKC100MCT-ND | Stackpole HVCB1206FKC100M | 19,674 | 4.01 |
| R8, R9 | 311-100KHRCT-ND | YAGEO RC0603FR-07100KL | 916,017 | 0.10 |
| R10 | 311-100HRCT-ND | YAGEO RC0603FR-07100RL | 260,261 | 0.10 |
| U2 | 1568-12918-ND | SparkFun 12918 (BOB-12918) | 656 | 6.95 |
| U3 | LMP7721MA/NOPB-ND | TI LMP7721MA/NOPB | 2,191 | 7.34 |
| U4 | MCP6002-I/SN-ND | Microchip MCP6002-I/SN | 11,665 | 0.42 |
| X1 | S7008-ND | Sullins PPTC101LFBN-RC | 24,605 | 0.64 |
| X2 | S7004-ND | Sullins PPTC061LFBN-RC | 30,030 | 0.47 |
| stacking headers | 1528-1074-ND | Adafruit 85 | 814 | 1.95 |

**Changed on 2026-09-25 for Digi-Key:** C2 (Murata GRM1885C1H100JA01D is *Not For New Designs*) → Samsung
CL10C100JB8NNNC, same 10 pF C0G 50 V 0603. C3/C7 (Samsung CL10B104KB8NNNC, 0 in stock, 61-week lead
time) → Würth 885012206095, same 100 nF X7R 50 V 0603. C4 (Samsung CL21A106KAYNNNE, 0 in stock) → Taiyo
Yuden TMK212BBJ106KGHT, same 10 µF X5R 25 V 0805 (1.35 mm max height). R4: the old number 10KQBK-ND no longer
shows up at Digi-Key; same Yageo part under 13-CFR-25JB-52-10K-ND. The `LCSC` column in `BOM.csv` is only for
the optional JLC route and may name an equivalent part (R6: Uniroyal), not the Digi-Key MPN.

**Watch before ordering:** C5/C6 had only 734 in stock (2 needed); if it has run out, any 1 µF ≥ 16 V X5R/X7R 0603 will do. The LMP7721 has **no pin-compatible substitute**: if LMP7721MA/NOPB-ND is gone, LMP7721MAX/NOPB is
the same part on a reel (drop-in; check whether Digi-Key sells it as cut tape); anything else (e.g. ADA4530-1,
LMC6001) has a different pinout/package and means a PCB respin.

**Cost** (Digi-Key qty-1 prices, USD, parts only, excl. PCB, shipping and VAT): **1 board $36.40,
2 boards $72.80** (Teams 4+5 may want a spare). The two biggest items are J5 SMA ($9.98) and U3 ($7.34).

**Recommended spares** (cheap, and small parts get lost or damaged in hand-soldering):
- 0603/0805 passives and CR3: order **10 of each line** instead of 1–3 (price per piece drops to $0.03,
  so 10 cost about the same as 3–4), i.e. +20–50 % is the minimum.
- 1 extra LMP7721 ($7.34): it is the critical, ESD-sensitive part; 1 extra R6 ($4.01): it is easy to
  contaminate. 1 extra MCP6002, +2 of each THT resistor and 1N4148, +1 C1.
- For 2 boards plus these spares: **about $87**.

### The bare PCB: DigiKey PCB Builder

Digi-Key does not make or assemble boards itself; its **PCB Builder** (digikey.com/en/pcb-builder, needs a
My DigiKey login to check out) uploads your files and shows live offers from partner board houses, which ship
directly to you: **DKRed** (Digi-Key's own budget programme, built in Hollister CA), Summit Interconnect,
Advanced Circuits and Precision PCBs.

- **Files:** upload `fab/mie1001_daq_simple_gerbers.zip` (RS-274X Gerbers + Excellon drill, < 10 MB).
  Digi-Key requires at least 2 copper layers, a drill file, 2 solder-mask layers and an outline; the zip
  has all of them (F/B_Cu, F/B_Mask, F/B_Silkscreen, Edge_Cuts, PTH + NPTH drill). Digi-Key's FAQ lists
  extensions such as .gts/.gto/.drl/.gko and does not name KiCad's `.gtl/.gbl/.gm1`: check the viewer
  and assign top copper = `.gtl`, bottom copper = `.gbl`, outline = `.gm1` by hand if it guesses wrong.
  F_Paste and the `.gbrjob` are not needed (no stencil: hand-soldered).
- **Capabilities vs this board (checked from the .kicad_pcb, not just the rules):**

  | | this board | DKRed | Advanced Circuits / Summit / Precision |
  |---|---|---|---|
  | layers, thickness | 2, 1.6 mm FR4 | 2 or 4, 0.062" (1.6 mm) FR4 Tg170 | 2/4/6, 0.031/0.062/0.093" |
  | min track / space | 0.5 mm / ≥ 0.3 mm (DRC min), zone min width 0.2 mm | 5 mil (0.13 mm) | 5, 6 or 8 mil |
  | min drill | 0.4 mm (vias) | 8 mil (0.20 mm) | 8, 11 or 12 mil |
  | annular ring | ≥ 0.2 mm (vias 0.8/0.4), ≥ 0.27 mm pads | ≥ 3 mil | – |
  | board size | 68.58 × 53.34 mm (2.70 × 2.10 in) | 0.5–10 in | AC 0.75–10 in, Summit 2–16 × 2–22 in, Precision 1–18 in |
  | finish / mask | guard copper deliberately without mask | **ENIG only**, red mask, white silk | HASL (leaded or lead-free) or ENIG; green/black/red/blue/purple/clear mask |

  **Nothing fails**: every rule has ≥ 2× margin. The unmasked guard ring is just openings in the
  F/B_Mask Gerbers, which every house reproduces; the mask web between the bare guard and any other copper
  is ≥ 0.4 mm. ENIG (DKRed's only option) is the better finish here anyway: flat pads for the SOIC/0603 parts and
  gold on the exposed guard copper. If you pick another house, choose ENIG or lead-free HASL.
- **Price:** DKRed is $1.50 per square inch per board, **minimum 4 boards**: 5.67 in² → $8.50/board,
  **$34 for 4** (you cannot order just 3; 4 is the cheapest option). Build time 10 business days (5 quick-turn).
  The other houses quote live after the upload (not published; typically more). DKRed ships free only within
  the US: shipping to the Netherlands, customs and VAT are extra: check the total at checkout before committing.

### Optional: JLCPCB instead

Only if procurement allows it. Upload the same gerber zip (2 layers, 1.6 mm, HASL or ENIG). To have JLC
assemble the SMD preamp parts, turn on PCB Assembly (top side) and upload `fab/jlcpcb_bom.csv` and
`fab/jlcpcb_cpl.csv` (16 parts, 11 lines, from the `LCSC` column); check U3/U4/CR3 rotation in JLC's preview
and that the LCSC parts are in stock. Then solder only the THT steps below.

## Hand-soldering order

Nothing is assembled by the board house. Work on an ESD mat with a grounded wrist strap, fine tip
(≤ 1 mm chisel), 0.5 mm solder, flux pen, fine tweezers and a magnifier. Solder **all SMD parts first**,
while the board still lies flat, then the THT parts from lowest to tallest.

1. [ ] **U4 MCP6002 (SOIC-8)**: tack one corner pin, check pin 1 (dot) and alignment, solder the opposite
   corner, then the rest. Remove any bridge with wick.
2. [ ] **U3 LMP7721 (SOIC-8)**: **ESD-sensitive** (wrist strap; leave it in its bag until needed), pin 1 at the
   dot. Pins 1 and 8 sit in the bare guard pocket: use little solder, no bridge to the guard copper.
3. [ ] **CR3 BAV199 (SOT-23)**: small; tack the single pin first, then the two others.
4. [ ] **0603 parts**: R5, R7, R11 (1k), R8, R9 (100k), R10 (100R), C2 (10 pF, unmarked: keep it apart
   from the other caps), C3, C7 (100 nF), C5, C6 (1 µF). Ceramic caps are unmarked: open one tape at a time.
5. [ ] **0805 C4** (10 µF) and **1206 R6** (100 MΩ; don't touch the resistor body with bare fingers).
6. [ ] **Clean the preamp area now**: scrub U3, R6, C2, R4/CR3 and the guard ring with IPA (≥ 99 %) and a
   clean brush, rinse with fresh IPA, let it dry fully (heat gun on low / 30 min). **Critical for the pA
   input:** any flux residue across the guard is a leakage path.
7. [ ] THT, lowest first: CR1, CR2 (lying flat, **stripe towards the K**), R1, R2 (flat), C1, R3 and R4
   (standing, body on the circle).
8. [ ] **J5 SMA**: the four ground legs are on the GND pour and soak heat: use a larger tip / higher
   temperature (~370 °C) and let the solder flow through; the centre pin sits in the bare VREF guard ring:
   no solder bridge from a ground leg to the ring (check with a meter).
9. [ ] Female headers X1 (1×10), X2 (1×6), J4 (plug the breakout in while soldering so they stay straight),
   terminal blocks J1–J3, then the stacking headers (last: tallest).
10. [ ] **Trim every lead under the board flush. This is required, not optional.** The ADS1115 socket
   and J4 sit right above the UNO's ATmega chip, and CR1, CR2 and C1 are in the same band. An untrimmed
   socket lead sticks out about 1.6 mm and a terminal pin about 2.9 mm. Check the clearance over the rest
   of that area with the real boards before you solder everything down.
11. [ ] Clean the whole board (IPA) once more around J5 and the guard ring; handle the board by its edges.
12. [ ] Plug the breakouts in **component side up**, matching the pin names on the breakout to the names on
   the shield: VDD on the left for the ADS1115, and OUT at the top (at the ▼) for the MCP4725. Rotated
   180° the MCP4725 gets 5 V on its GND pin.

**Hard to hand-solder:** the 0603 parts (small, unmarked caps: C2 mixed up with another cap ruins the
preamp's stability), CR3 (SOT-23), and J5 (ground legs on a big pour, next to the bare guard). U3 is easy to
solder but easy to kill with ESD and easy to spoil with flux: this is why it gets a spare. None of the parts
needs hot air or reflow.

## Firmware notes

- ADS1115 at **0x48**, MCP4725 at **0x60**. Libraries: Adafruit ADS1X15 and Adafruit MCP4725.
- **`dac.begin(0x60)`**: the Adafruit_MCP4725 library defaults to 0x62, so a plain `dac.begin()`
  finds nothing. `ads.begin()` (0x48) is correct as is.
- Read the signal on A0. `ads.setGain(GAIN_TWOTHIRDS)` gives ±6.144 V full scale. For a small
  signal turn the gain up instead of adding an amplifier: `GAIN_SIXTEEN` gives ±0.256 V full scale
  and ~7.8 µV steps.
- **The input is filtered at 339 Hz** (R2 with C1), so the board cannot follow anything faster.
  Leave C1 out if you need the bandwidth.
- **For 50 Hz mains hum, average in the sketch over whole 20 ms windows**, not over "a slow data
  rate". At 8 SPS one conversion takes 125 ms = 6.25 mains cycles, and the ADS1115's filter nulls
  sit at multiples of its data rate (8, 16, 24 Hz ...), not at 50 Hz, so 8 SPS does not by itself
  cancel hum. Instead take readings at a fixed rate that fits a whole number of times into 20 ms and
  average an integer number of 20 ms windows: e.g. 250 SPS (`RATE_ADS1115_250SPS`, 4 ms) and average
  5, 10, 50 ... consecutive readings (20, 40, 200 ms). Time the samples with the ALRT/RDY pin (D2),
  not with `delay()`. C1 barely touches 50 Hz. Measure the result with the input shorted.
- **J4 is a monitor header, not three spare inputs any more.** J4-1 is PRE_OUT (the preamp output via
  R11) and J4-3 is VREF (the MCP6002 output via R10): **never connect either to GND or to a source**,
  that shorts an op-amp output. Connect only a meter or scope. J4-2 is ADS1115 A2, which carries the
  QPS read-back while JP1 is bridged; only if you cut JP1 is it a free input, and then it has no
  resistor, clamp or filter: keep it within 0 V … VDD. Leaving A2 open is fine (the firmware just
  doesn't read it); there is nothing to tie down.
- **The useful input range is 0 V to VDD** (the USB 5 V, often only 4.8 V). This board expects a
  voltage from Team 3's preamp, not the raw detector current. R2 protects the chip from a preamp
  that overshoots, but readings above VDD are not valid.
- The MCP4725 powers up at mid-scale (2.5 V on QPS OUT). Write 0 to its EEPROM once.
- Trigger in: `pinMode(8, INPUT)`, active HIGH. R3 holds D8 low when nothing is connected. Use 5 V
  logic if you can: the ATmega needs 3.0 V for a HIGH, so 3.3 V logic (3.27 V at D8 after the R1/R3 divider) has under 0.3 V to spare.
  R1 limits the current if the trigger goes a little above 5 V. **Never feed it 12 V**: that pushes
  6.5 mA into the ATmega's input clamp, past its absolute maximum.
- ALRT goes to **UNO pin 2**: `pinMode(2, INPUT)` is enough, the breakout has the pull-up. (The diodes are named CR1 and CR2 and the UNO is ARD1, so "D2" and "A1" on this board
  always mean the UNO's pins.)

## Compared with the full board (`../mie1001_daq_board`, rev E)

Since rev D this board also has an electrometer preamp (U3 LMP7721, 100 MΩ, guarded input on J5), so
it can measure a Faraday-cup current directly, with a single fixed range (~25 nA full scale). SIGNAL IN
(J1) still digitises a voltage that someone else has made, with basic protection (R2, CR1/CR2) and a
339 Hz filter (R2, C1). The full board (`../mie1001_daq_board`) adds a jumper-selectable second
feedback range (2.2 MΩ / 100 MΩ); this one stays easy to build, with the breakouts from class plugged in.

## Files

`generate_schematic.py` and `generate_pcb.py` generate everything (the PCB script reuses the
UNO geometry and the router of the full board); `./build.sh` rebuilds and re-runs all checks.
The possum and the prayer to the machine gods are in `generate_pcb.py`, `possum()`.

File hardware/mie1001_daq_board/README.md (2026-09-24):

# MIE1001 Team 5 — DAQ shield for Arduino UNO R3 (rev E)

Data-acquisition shield for the portable quadrupole mass spectrometer. It measures the
detector current (pA to µA) with an electrometer transimpedance amplifier and a 16-bit
ADC, and drives the QPS mass command with a 12-bit DAC. It plugs onto an Arduino UNO R3
and takes all power from the UNO's 5 V rail.

```
detector -> J1 BNC -> R14 10k -> D1 clamp to VREF -> R4 1k -> U4 LMP7721 TIA (2M2 / 100M via JP1)
         -> R3/C2 1k/1uF anti-alias -> U2 ADS1115 AIN0 (AIN1 = VREF via R16/C10) -> I2C -> UNO -> USB
VREF: R7/R8 divider + C3 10uF -> U3B buffer -> R15 100R -> VREF + C9 1uF (-> R17 -> U4 IN+, guard, D1)
UNO -> I2C -> U1 MCP4725 -> U3A MCP6002 buffer -> R12 100R -> J2 -> Extrel QPS mass command
                                                          \-> R13 -> ADS1115 AIN2 (read-back)
Team 4 sequencer -> J4 -> R9/R10 -> UNO D8 (trigger)     U2 ALERT/RDY -> R11 pull-up -> UNO D2
```

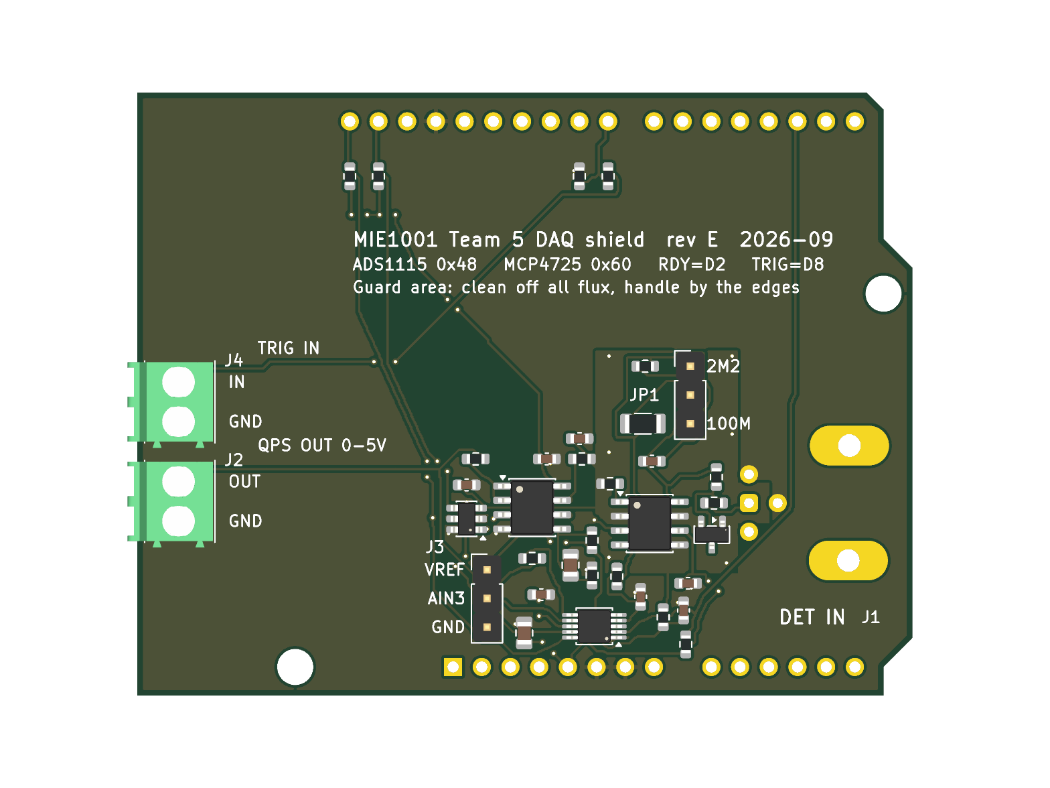
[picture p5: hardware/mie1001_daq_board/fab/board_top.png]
board


## Status

| Check | Result |
|---|---|
| ERC (schematic) | 0 errors, 0 warnings |
| DRC (layout), incl. schematic parity | 0 errors, 0 unconnected, 0 parity issues |
| DRC warnings left | 4 × `lib_footprint_mismatch`: J1, J2, J4, A1 are deliberately modified copies (see *Layout*) |
| Guard check (`check_guard.py`) | 0 unexpected items: no copper of any other net within 1.0 mm of BNC_IN / DET_IN / TIA_IN / TIA_REF, except the BNC's own shell pins (0.98 mm, connector geometry). 22 input items have no VREF guard copper within 0.6 mm: R14.1 and the BNC centre-pin trace (squeezed between the BNC's pins), JP1.2, and 19 segments of the TIA_IN run from C1 to JP1. Those are bordered by the feedback nets (TIA_OUT, RF_100M), whose leakage only adds in parallel with the feedback resistor, not by +5 V or GND |
| Orientation | Matches a real UNO R3 seen from the top (rev D was mirrored, see below). **Still do the 1:1 paper check** |
| SMD parts | JLC assembles 31 parts (15 BOM lines). **R14 is hand-soldered** from the Digi-Key order (anti-surge, no verified LCSC stock). C15849 (1 µF, JLC *basic*) showed no stock on LCSC's shop on 2026-09-22 and the LMP7721 (C124427) only ~60 pcs: confirm both when ordering |

## Files

| File | What it is |
|---|---|
| `generate_schematic.py` | writes the schematic, symbol library and `BOM.csv` |
| `generate_pcb.py` | writes the PCB: placement, routing (built-in grid router), guard and ground pours |
| `check_guard.py` | leakage check around the pA input node |
| `make_fab.py` | JLCPCB BOM/CPL + gerber zip |
| `build.sh` | runs all of the above plus ERC, DRC and the exports |
| `mie1001_daq_board.kicad_pro/.kicad_sch/.kicad_pcb` | the KiCad 10 project (open the `.kicad_pro`) |
| `mie1001_daq_board.pdf` | schematic plot |
| `BOM.csv` | full BOM: manufacturer, MPN, Digi-Key P/N **and LCSC P/N** |
| `fab/mie1001_daq_shield_gerbers.zip` | gerbers + drill, upload this to JLCPCB |
| `fab/jlcpcb_bom.csv`, `fab/jlcpcb_cpl.csv` | JLCPCB assembly BOM and pick-and-place |
| `fab/assembly_top.pdf`, `fab/board_top.png` | assembly drawing and render |

**Both files are generated.** Edit the Python, then run `./build.sh`. Editing the
`.kicad_sch`/`.kicad_pcb` in the GUI works, but the next `./build.sh` overwrites it.

## What changed in rev E (independent critical review, 2026-09-22)

| Change | Why |
|---|---|
| **Board no longer mirrored** | KiCad's `Module:Arduino_UNO_R3` footprint is drawn from the back (kicad-footprints #864). Rev D used it as-is, so its headers, jacks and holes were a mirror image of a real UNO and the shield could not plug in. The footprint is now flipped and every coordinate goes through the corrected transform. The central block's *placement* was moved as one piece (a translation as seen from the top, so parts keep their positions relative to each other); all *routing* was redone and every check was re-run on rev E |
| **R14 10k anti-surge** (Panasonic ERJ-PA3F1002V, AEC-Q200, pulse-rated) between the BNC and the clamp | A discharge on the BNC went straight through D1 into VREF. R14 limits it; drop is 10 µV per nA. A plain thick-film 0603 was not rated for the pulse; a 1206 would not fit without crossing the input traces |
| **VREF buffered and decoupled**: R15 100 Ω + C9 1 µF, C3 100 nF → 10 µF | VREF had no capacitor and fed the LMP7721 IN+, AIN1 and the clamp directly; USB ripple passed the divider |
| **R17 1k into LMP7721 IN+**, **R16/C10 1k/1 µF into AIN1** | IN+ protection; AIN1 now sees the same 1k/1 µF as AIN0, so the ADC input offsets match |
| **LMP7721 pin 5 (N/C) on the guard** | It floated next to the input |
| Router keeps every other net ≥1.2 mm from the input nets | The review found the RDY track 0.23 mm from the BNC centre pin; `check_guard.py` now names every nearby item and fails on anything unexpected |
| Guard widened around IN+ and the BNC centre pin | Ground pour was 0.7–0.94 mm from input copper |
| Silkscreen ≥ 1.0 mm text | 0.8 mm was below the legible minimum |
| BNC mounting pegs stay unconnected | They are unnumbered pads with no schematic pin (netting them breaks the parity check); the shell is grounded through pins 2–4 |
| **Outline corner fixed** (second review) | The lower-right chamfer had been copied wrong since rev D: it now runs (38.1, 0) → (40.64, 2.54) like the UNO drawing |
| **Keep-outs** over the 328P ICSP header moved/enlarged, one added over the 16U2's ICSP1 header; keep-outs now respect a via's/track's full width; all vias tented | Second review: the ICSP keep-out was offset, and +5 V vias sat untented above ICSP1 |
| **JLCPCB rotations corrected** in `fab/jlcpcb_cpl.csv`: SOIC +270°, SOT-23/SOT-23-6 −90° (JLCKicadTools table) | Raw KiCad angles would place U1, U3, U4 and D1 90° off. **The MSOP (U2) has no known offset: check it in JLC's preview** |
| BNC and block moved 0.6 mm down, J1 label beside the BNC, guard stitching vias always placed (6) | BNC pegs clear the ICSP header; a stitching via could previously be skipped silently |

### Input bias: the one trade-off kept on purpose
The TIA holds its input at VREF = 2.5 V, while the BNC shell, the cable shield and the
vacuum chamber are at GND. Any insulation between the detector wire and ground (cable,
feedthrough, detector mount) therefore sees 2.5 V and leaks 2.5 pA per TΩ into the
measurement. With PTFE coax (~10¹⁴–10¹⁵ Ω) that is ~0.003–0.03 pA; a clean dry feedthrough
~0.25 pA; a dirty or humid one a few pA. It is a near-constant offset that the per-scan
beam-off baseline removes. Moving the input to 0 V needs a negative supply (charge pump) next
to the pA node, which was judged not worth the risk. **Measure it at bring-up** (step 7).

## What changed from rev C (datasheet check, 2026-09-22)

| Change | Why | Source |
|---|---|---|
| TIA op-amp MCP6004 → **LMP7721** (U4) | MCP600x input bias is ~1 pA typical with **no max**, rising to ~19 pA at 85 °C: as large as one ADC count (0.625 pA at ±2.048 V on 100 MΩ). LMP7721: **±20 fA max** at 25 °C, Vos 150 µV max | TI SNOSAW6E Table 6.6; Microchip DS20001733L |
| **D1 clamp tied to VREF** instead of GND/5 V | At 2.5 V reverse bias each BAV199 diode leaks ~20–50 pA straight into the measured current. At 0 V bias the leakage is ~0. Still clamps at VREF ± 0.6 V | onsemi BAV199LT1G Fig. 4 |
| Quad MCP6004 → **dual MCP6002** (U3) | Only two buffers are left (DAC, VREF); no unused sections to terminate | DS20001733L Table 3-1 |
| R3/C2 10k/100nF → **1k/1µF** | Same 159 Hz corner, but the ADS1115 input current through 10k made a ~4 mV offset (~40 pA equivalent) | TI SBAS444 §5.5 |
| **R12 100 Ω** on the QPS output | MCP6002 driving >100 pF of cable needs an isolation resistor | DS20001733L §4.3 |
| **AIN2 reads the QPS output back** (via R13) | The DAC's reference is the USB 5 V rail (±5 %). The ADS1115 has its own reference, so firmware can measure what the QPS really gets | MCP4725 DS22039D §5.3 |
| **I²C on the dedicated SDA/SCL pins only** | A4/A5 are I²C only on the UNO; SDA/SCL also work on UNO R4, Leonardo and Mega | Arduino A000066 |
| BNC pads 3/4 now grounded | The footprint has three shell pins; the old symbol only connected one | KiCad footprint |
| Terminal blocks 5.08 mm → **3.5 mm** (Phoenix 1984617) | Two 5.08 mm blocks do not fit between the UNO's DC and USB jacks | — |
| 100 MΩ for JLC assembly: **Uniroyal 1206W4F1006T5E** (C59781) | Stackpole HVCB has no LCSC stock. 1 %, ±100 ppm/°C instead of ±50 | LCSC |

## Layout

- **Outline** is the UNO R3 shape, 68.6 × 53.3 mm, 2 layers, in the real orientation (rev E).
- **Guard**: a VREF copper pour on **both** layers surrounds the whole TIA input node
  (U4 pins 1/8 with guard pins 2/7, R4, C1, JP1 pin 2, D1, and a finger between the BNC
  centre pin and its shell pins). The guard area is cut out of both ground pours, and
  only VREF may use bottom copper or vias near the input copper (LMP7721 datasheet §10.1).
- **Ground**: poured on both layers, a via at every SMD ground pad.
- **Keep-outs**: no bottom copper and no through-hole leads above the UNO's USB-B jack,
  DC jack and ICSP header. With standard stacking headers the shield rests on the USB shell.
- **Mounting holes**: two of the UNO's four holes are used (near the power header and at the
  right end). The one near the BNC would put an M3 head under the BNC flange; the one next to
  SDA/SCL would hit the stacking header of the R3 SCL pin.
- **Rules**: 0.2 mm tracks, 0.2 mm clearance (0.15 mm inside the ADS1115's own TI land
  pattern), 0.6/0.3 mm vias. JLCPCB's standard process allows 0.127/0.127 mm.
- Modified footprints (hence the 4 library-mismatch warnings): the UNO footprint's
  silkscreen/courtyard drawing of the whole UNO is removed; J1/J2/J4 outlines that cross
  the board edge are moved to the fab layer; J1's shell pins connect solid to ground.

## Ordering from JLCPCB

1. **PCB**: upload `fab/mie1001_daq_shield_gerbers.zip`. 2 layers, 1.6 mm, **ENIG**
   recommended (flat pads for the 0.5 mm-pitch ADS1115, cleaner guard), any colour.
2. **Assembly**: *PCB Assembly* → top side → upload `fab/jlcpcb_bom.csv` and
   `fab/jlcpcb_cpl.csv`. 31 parts, 15 lines; U1–U4, D1 and R2 are *extended* parts
   (small extra fee each).
3. **Check the rotation preview.** The CPL already carries JLC's offsets for SOIC and
   SOT-23, but make sure the pin-1 dot of **U1, U2, U3, U4 and D1** lands on the pin-1
   mark, and fix it in the preview if not. **U2 (MSOP-10) is the likeliest to need it.**
4. Hand-solder from the Digi-Key order (`BOM.csv`): **R14** (0603, ERJ-PA3F1002V), J1 BNC
   (031-6575), J2/J4 terminal blocks (1984617), J3 1×3 header, JP1 1×3 header + jumper,
   and the UNO stacking headers. **Trim every through-hole lead flush (≤ 1 mm)**: the BNC
   sits above the UNO's ATmega328P DIP and beside its ICSP header, J3 beside the UNO's
   electrolytic capacitor, J2/J4 above the regulator area.

## Bring-up

0. **Before ordering: print `fab/assembly_top.pdf` at 100 % and lay a real UNO on it.**
   The headers must line up pin for pin, the USB-B and DC jacks must sit under the empty
   left end, the ICSP header must not sit under the BNC pegs. Then measure, on the real
   UNO + stacking headers, the gap from the UNO surface to the shield underside, and the
   height of the ATmega328P in its socket, both ICSP headers and the electrolytic caps:
   each must stay below the gap minus the trimmed lead length.
1. Before plugging into the UNO: check 5 V to GND is not a short.
2. Plug in, power from USB. VREF on J3 pin 1 should read **half of the measured 5 V rail**
   (±1 %), i.e. about 2.4–2.6 V on USB.
3. I²C scan: **0x48** (ADS1115) and **0x60** (MCP4725).
4. **Program the MCP4725 EEPROM to 0x000 once.** From the factory it powers up at
   mid-scale, so the QPS gets 2.5 V every time the board powers on (DS22039D Table 5-3).
5. DAC: write codes, read J2 with a meter and with AIN2; they should agree to a few mV.
6. TIA, jumper on 100 M: open BNC → reading within a few counts of VREF (the offset
   is dominated by the ADC, not the LMP7721). Then a known current, e.g. 1 V through a
   1 GΩ resistor into the BNC = 1 nA → 100 mV below VREF.
7. With the real detector and cable connected and the beam off, log the TIA offset for a
   few minutes (see *Input bias* above). A stable offset within a couple of ADC counts is
   fine; large or drifting means leaky insulation: clean and dry the feedthrough first.
8. **Clean the guard area** with isopropanol after any hand soldering near it. Flux and
   fingerprints leak more than the LMP7721 does.

## Firmware notes

- ADS1115: read AIN0 vs AIN1 differentially. The TIA swings ±2.5 V around VREF, so pick
  the PGA range by what you need:
  - ±4.096 V: whole swing, 1.25 pA/LSB and 25 nA full scale on 100 MΩ (57 pA/LSB, 1.1 µA on 2M2)
  - ±2.048 V: finer, 0.625 pA/LSB, but clips beyond 20 nA on 100 MΩ (28 pA/LSB, 0.93 µA on 2M2)

  Use ALERT/RDY on D2 as the conversion-ready interrupt.
- QPS read-back on AIN2 (single-ended, 0–5 V) needs the **±6.144 V** PGA range: at ±4.096 V it
  clips above 4.096 V. The ADS1115 still cannot read above VDD + 0.3 V.
- Current sign: a Faraday cup collecting positive ions pulls TIA_OUT **below** VREF; an
  electron-multiplier anode pushes it above. Either works; the swing is ±2.5 V.
- Subtract a baseline (beam off) per scan: this removes the remaining offsets.
- Trigger in (J4) expects 3.3–5 V logic. R9 (1 kΩ) limits the clamp current if it is
  driven slightly above 5 V; do not connect anything above ~6 V.

## Known limitations

- **QPS command is 0–5 V, not the Extrel's 0–10 V.** Gain 2 needs a ≥12 V rail; not on a
  USB-powered shield.
- The board carries the TIA and DAC that the project note assigns to Teams 3 and 4.
  Deliberate (removes the dependency on a preamp that may not exist) but agree the split
  in writing.
- Guard traces are under solder mask. TI recommends exposed guard copper; that needs a
  mask opening and a careful clean, left out for manufacturability.

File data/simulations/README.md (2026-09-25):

# Simulations (NOT measured data)

`basic.py` simulates `firmware/MCP4725_sine_scope`: the sketch's own logic (64-point sine, `sine[i] / 4`,
`analogRead(A0)`) with the DAC and the Uno ADC modelled on the same 5 V rail, the +1 count offset measured at
code 3584 on 24 Sept, and ~0.5 count noise. `plotter_look.py` draws it in the style of the Arduino IDE 2
Serial Plotter, with a banner saying it is a simulation. The sketch was run on the breadboard, but no
screenshot was kept.

`basic.py` also re-draws the real 20 Sept ADS1115 self-test numbers in the same style
(`../2026-09-20_selftest/fig_ads_selftest_plotter_style.png`, labelled as real data).

Run: `pip install numpy matplotlib && python basic.py`

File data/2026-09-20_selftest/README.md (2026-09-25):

# Self-tests on the real Uno, 20 September 2026

Serial output of `firmware/ADS1115_selftest` and `firmware/MCP4725_standalone_test` from the first
breadboard session, copied from what was pasted in the team chat that day. The measurements are real;
the two figures are re-plotted / re-typeset from those numbers (not screenshots of the IDE).

- `ads_selftest_2026-09-20.txt` - the 17 repeated ADS1115 readings (raw counts, GAIN_TWOTHIRDS, 0.1875 mV/count):
  A0 = 3.3 V pin, A1 = GND, A2 = 5 V pin, A3 = floating.
- `fig_ads_selftest.png` - the readings, and each channel's scatter around its mean.
  Grounded input: 1.1 counts rms (0.2 mV); 3.3 V pin: 0.8 counts (0.15 mV).
- `fig_serial_monitor_debug.png` - the debugging sequence, shortened: ADS1115 not found until the wiring was
  fixed, then all channels PASS; MCP4725 with SDA/SCL stuck low, then no chip, then PASS
  (DAC 3584 -> Uno A0 896, expected 895; DAC 4095 -> 1023).

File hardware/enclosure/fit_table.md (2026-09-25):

| Check | Enclosure | Part | Clearance mm | | Note |
|---|---|---|---|---|---|
| USB-B jack, sides | notch y 31.1..45.1 | jack y 32.1..44.1 (A000066) | 1.00 | OK |  |
| USB-B jack, bottom | notch floor z 9.0 | jack bottom = UNO top z 10.0 | 1.00 | OK |  |
| USB-B jack, top | lid wall edge z 22.0 | jack top z 21.0 | 1.00 | OK | jack_h assumed 11.0 |
| USB-B jack, reach | outer wall x -4.4 | jack front x -6.5 | 2.10 | OK | info: protrudes, plug mates fully |
| DC jack, sides | notch y 1.2..12.8 | jack y 2.4..11.6 | 1.20 | OK |  |
| DC jack, bottom/top | z 9.0..22.0 | jack z 10.0..21.0 | 1.00 | OK |  |
| DC jack, plug reach | outer wall x -4.4 | jack front x -1.6 | 2.80 | OK | info: jack front recessed; plug sleeve 9.5 mm long, body must be <= 11.6 dia |
| J1 wire entries (y) | slot y 12.3..30.8 | entries y 15.44, 18.94 (3.5 pitch) | 1.60 | OK | clearance to a 3 mm wire/ferrule |
| J1 wire entry (z) | slot z 22.0..29.0 | entry centre z 26.5 | 1.00 | OK | wire_z assumed shield+3.9 |
| J1 body vs lid wall | inner wall x -2.00 | body x -0.91..6.78 (courtyard - 0.5) | 1.09 | OK |  |
| J3 wire entries (y) | slot y 12.3..30.8 | entries y 24.24, 27.74 (3.5 pitch) | 1.59 | OK | clearance to a 3 mm wire/ferrule |
| J3 wire entry (z) | slot z 22.0..29.0 | entry centre z 26.5 | 1.00 | OK | wire_z assumed shield+3.9 |
| J3 body vs lid wall | inner wall x -2.00 | body x -0.91..6.78 (courtyard - 0.5) | 1.09 | OK |  |
| J2 wire entries (y) | slot y 11.4..21.1 | entries y 14.54, 18.04 (3.5 pitch) | 1.59 | OK | clearance to a 3 mm wire/ferrule |
| J2 wire entry (z) | slot z 22.0..29.0 | entry centre z 26.5 | 1.00 | OK | wire_z assumed shield+3.9 |
| J2 body vs lid wall | inner wall x 70.58 | body x 61.79..69.48 (courtyard - 0.5) | 1.10 | OK |  |
| J1+J3 screw window | x -0.6..5.2, y 13.4..29.7 | screws over clamp, 2.5-3 mm blade | 1.00 | OK | info: window width vs 3 mm blade; lid ceiling 7.3 above terminal top |
| J2 screw window | x 63.3..69.2, y 12.5..20.0 | screws over clamp, 2.5-3 mm blade | 1.00 | OK | info: window width vs 3 mm blade; lid ceiling 7.3 above terminal top |
| J4 Dupont slot | x 41.67..53.83, y 12.27..16.81 | socket x 42.67..52.83, y 13.27..15.81 | 1.00 | OK |  |
| J5 SMA -> BNC adapter | hole dia 12.5 at (58.34,43.54) | SMA nut 8 mm hex (9.2 a/c) | 1.65 | OK | radial |
| J5 adapter BNC studs | hole dia 12.5 | BNC bayonet studs 11.6 across | 0.45 | OK | info: radial, only while threading the lid over the adapter |
| Breakouts vs lid ceiling | ceiling z 39.1 | breakout top z 37.1 | 2.00 | OK | brk_h assumed 14.5 |
| Stacking headers vs ceiling | ceiling z 39.1 | header top z 31.1 | 8.00 | OK |  |
| Boards vs side walls (x) | x -2.0 / 70.58 | outline x 0 / 68.58 | 2.00 | OK |  |
| Boards vs front/back walls | y -1.5 / 54.84 | outline y 0 / 53.34 | 1.50 | OK |  |
| Lid-screw posts vs board corners | post r 4.0 | UNO outline corners | 1.32 | OK |  |
| Boss/peg H1 vs shield hole | at (13.97,2.54) | PCB H1 (13.97,2.54) | -0.00 | OK | info: position error (0 = exact) |
| Boss/peg H2 vs shield hole | at (66.04,7.62) | PCB H2 (66.04,7.62) | -0.00 | OK | info: position error (0 = exact) |
| Boss/peg H3 vs shield hole | at (66.04,35.56) | PCB H3 (66.04,35.56) | -0.00 | OK | info: position error (0 = exact) |
| Spacer at H3 vs UNO ICSP header | spacer dia 5.6 at y 35.56 | ICSP keep-out y max 32.14 | 0.62 | tight | keep-out is already larger than the header |
| Preamp guard vs nearest wall | back wall y 54.84 | guard y max 48.14 | 6.70 | OK | info: nothing of the enclosure is within 16.5 mm above it |

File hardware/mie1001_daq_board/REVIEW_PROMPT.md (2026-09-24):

You are reviewing a PCB before it is sent to JLCPCB for fabrication and assembly. A wrong
pin or a leakage path means a dead or useless board and a lost 2-3 weeks, so be sceptical,
verify against sources, and never assume. Do NOT modify any file. Report only.

## The design
Folder: ~/projects/mie1001_daq_board (KiCad 10). Read README.md first.
An Arduino UNO R3 shield for a portable quadrupole mass spectrometer:
- Detector current (pA to uA) -> BNC J1 -> R4 1k (+ BAV199 D1 clamp to VREF) -> LMP7721
  transimpedance amp U4 (feedback 2M2 or 100M via jumper JP1, C1 10pF) -> R3/C2 1k/1uF
  -> ADS1115 U2 AIN0, differential against AIN1 = VREF (2.5 V mid-supply, buffered by U3B).
- MCP4725 DAC U1 -> MCP6002 buffer U3A -> R12 100R -> J2 (QPS mass command, 0-5 V),
  read back on ADS1115 AIN2 via R13.
- I2C on the UNO's dedicated SDA/SCL pins; ADS1115 ALERT/RDY -> D2; trigger J4 -> D8.
- All power from the UNO 5 V (USB). 2-layer board, UNO R3 outline.
Both the schematic and the PCB are GENERATED by generate_schematic.py and
generate_pcb.py; ./build.sh rebuilds everything and runs ERC, DRC and check_guard.py.
Official datasheets are in datasheets/. Rendered images: fab/board_top.png,
fab/assembly_top.pdf, mie1001_daq_board.pdf (schematic).

## Rules for this review
- For every claim, cite the evidence: datasheet file + page/table, or file + line, or the
  command you ran and its output. If you cannot verify something, say "UNVERIFIED" instead
  of guessing. Do not answer from memory when a datasheet is in datasheets/.
- Run ./build.sh yourself and read erc.rpt and drc.rpt. Expected: ERC 0; DRC 0 errors,
  0 unconnected, 0 schematic parity issues, and exactly 4 lib_footprint_mismatch warnings
  (J1, J2, J4, A1 are deliberately modified copies). Anything else is a finding.
- Separate real defects from preferences. Rank findings by severity.

## Check each of these
1. PINOUTS. For U1 MCP4725A0T-E/CH (SOT-23-6), U2 ADS1115IDGSR (MSOP-10), U3 MCP6002-I/SN
   (SOIC-8), U4 LMP7721MA/NOPB (SOIC-8, non-standard pinout) and D1 BAV199LT1G (SOT-23):
   export the netlist (kicad-cli sch export netlist) and compare every pin's net with the
   datasheet pin table. Also check each symbol's pin numbers match its footprint's pad
   numbers, and that the UNO header pads (Module:Arduino_UNO_R3) match the UNO pinout.
2. ELECTRICAL. Supply and abs-max at 4.75-5.25 V for every part; ADS1115 inputs stay in
   GND..VDD; I2C addresses (expect 0x48 and 0x60); TIA stability with C1 = 10 pF for both
   feedback resistors and ~100 pF of detector cable; LMP7721 input common-mode range at
   VREF = 2.5 V; MCP6002 driving a cable through R12; the anti-alias filter vs the 860 SPS
   max data rate; what the QPS output does at power-up.
3. PICOAMP INPUT. The nets /TIA_IN and /DET_IN must be surrounded only by the VREF guard
   (pours on both layers) and feedback parts. Run check_guard.py and inspect the layout
   around U4, R4, C1, JP1, D1 and J1 pin 1. Report any other net closer than 1 mm, any
   leakage path from +5V or GND into those nets, and whether the guard really encloses them
   on both layers (compare with LMP7721 datasheet section 10, Layout).
4. POWER AND GROUND. Decoupling cap at each IC's supply pin, ground via at every SMD
   ground pad, ground pours not split into islands, no ground copper inside the guard.
5. MECHANICAL. Board outline and header positions vs the UNO R3 drawing
   (datasheets/Arduino_UNO_R3_A000066.pdf); the BNC J1 front flush with the right edge; no
   through-hole leads or bottom copper above the UNO's USB-B jack, DC jack or ICSP header;
   mounting holes; terminal blocks J2/J4 fitting between the DC and USB jacks.
6. MANUFACTURING. Track/clearance/drill vs JLCPCB standard 2-layer capabilities;
   fab/jlcpcb_bom.csv has an LCSC part for every SMD part and each LCSC number is the right
   part and package; fab/jlcpcb_cpl.csv rotations: for U1-U4 and D1, state what rotation
   JLCPCB will need so pin 1 lands on the pad-1 mark (KiCad and JLC zero angles differ).
7. SILKSCREEN AND USABILITY. Connector labels correct (J2: 1 = OUT, 2 = GND; J4: 1 = IN,
   2 = GND; J3: 1 = VREF, 2 = AIN3, 3 = GND; JP1: 1-2 = 2M2, 2-3 = 100M), pin-1 marks visible.

## Output
1. A verdict in one line: SEND TO FAB / FIX FIRST / DO NOT SEND.
2. Findings table: severity (critical / major / minor), what, where (file:line or
   ref+pad), evidence, suggested fix.
3. A list of everything you checked and found correct, with the evidence, so the team
   knows what was actually verified and what was not.
4. Anything you could not verify, and what a human should check by hand before ordering.

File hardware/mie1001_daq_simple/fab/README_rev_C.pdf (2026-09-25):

# MIE1001 — simple DAQ shield (rev C)

The beginner version of the DAQ board: an Arduino UNO R3 shield that the two breakout boards from class plug into. Through-hole parts only, fat tracks, everything hand-solderable. JLCPCB only makes the bare board; you solder it yourselves.

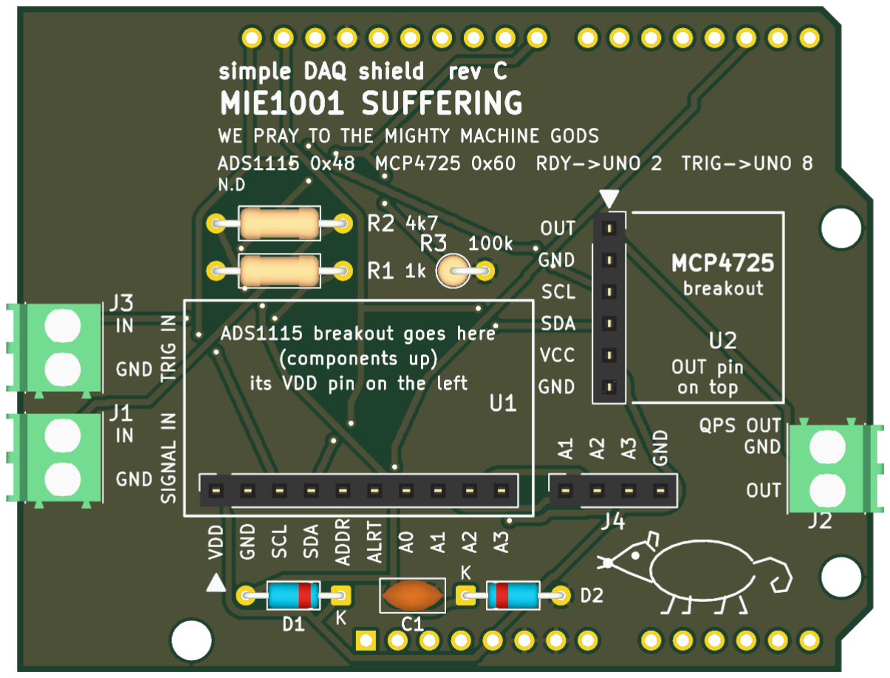
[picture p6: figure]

SIGNAL IN (J1) -> R2 4k7 -> [D1/D2 clamp, C1 filter] -> ADS1115 breakout A0 -> I2C -> UNO -> USB -> laptop
UNO -> I2C -> SparkFun MCP4725 breakout OUT -> QPS OUT (J2), 0-5 V
TRIG IN (J3) -> R1 1k -> UNO D8 (R3 100k to GND) | ADS1115 ALRT -> UNO D2 | spare A1-A3 on J4
Check | Result
ERC | 0 errors, 0 warnings
Independent critical review | Two reviews against the Adafruit, SparkFun, Arduino, Phoenix and TI source files and datasheets. Rev A: pinouts and UNO geometry correct, four fixes → rev B. Rev C: copper clean, no respin needed; one wrong BOM part number and several wrong claims in this file, all corrected below
9/23/26, 12:50 AM | MIE1001 simple DAQ shield
file:///tmp/claude-1000/-home-possum/72d223ad-2d6d-42c2-b6c6-65dd75786906/scratchpad/readme.html | 1/5

Still unverified | The height clearance between the underside of this shield and the UNO's ATmega chip. Nobody could find a dimensioned drawing: check it with the real boards
DRC incl. schematic parity | 0 errors, 0 unconnected, 0 parity issues (4 lib_footprint_mismatch warnings: A1 and J1–J3 are deliberately modified copies)
Orientation | Same real-UNO geometry as the full board (rev E): flipped library footprint, keep-outs over the USB, DC jack and both ICSP headers
Rules | 0.5 mm tracks, 0.3 mm gaps, 0.8/0.4 mm vias: far above JLCPCB's minimums

## What changed in rev C

Three parts on the signal input, in the free band under the ADS1115 socket:

C1 (100 nF) to ground. With R2 it is a single-pole low-pass at 339 Hz, and it supplies the charge the ADC's switched-capacitor input takes at each sample. It takes the edge off fast noise and limits the bandwidth, so leave it out if you need to measure something faster than ~300 Hz. It does not remove mains hum: at 50 Hz it attenuates by only 1.1 %. See the firmware notes for what actually works. C1 must be X7R or C0G, not Y5V (a Y5V part loses most of its value when warm, which moves the corner frequency anywhere up to ~2 kHz).
D1 and D2 (1N4148) clamps. They divert most of an over-voltage to the rails. Be clear about what does the work: R2 is what keeps the chip legal (1.3–2.4 mA at ±12 V against its 10 mA limit), because the 1N4148 only starts conducting around 0.5–0.7 V, by which point the input is already past the ADC's absolute maximum of VDD + 0.3 V and the chip's own internal protection diode is conducting alongside D1. The diodes are there for the energy of a static zap or a badly wrong connection, not to hold the pin inside spec. What the diodes cost: up to 25 nA of leakage each, which through R2 is up to 117 µV of offset (15 counts at GAIN_SIXTEEN, and several times worse when hot). Fine at low gain; calibrate the offset if you use the high gain ranges.
One side effect: with the Uno unpowered, a signal above 5 V feeds about 1.3 mA back into its 5 V rail through D1. Don't leave a live preamp connected to an unpowered board.
No amplifier. The ADS1115 has a programmable gain amplifier built in, so a small signal is handled in software with ads.setGain(...) instead of another chip. Note that at the highest gains the chip's differential input resistance falls to about 710 k, where R2 costs ~0.66 % of gain (0.02 % at the ±6.144 V range): calibrate if you use GAIN_SIXTEEN. Note TI suggests keeping a filter resistor under 1 k; 4.7 k is deliberate here, chosen for protection, and C1 at the pin supplies the sampling charge that the series resistance otherwise would.

Watch the stripe when soldering the diodes. The silkscreen prints K at the cathode end of each one, and that is the end with the black band on the part. D1's K points right, towards +5 V. D2's K points left, towards the signal. Backwards, they short the signal to a rail.

## What changed in rev B

R2 (4k7) in series with SIGNAL IN. The ADS1115 input may not go above VDD + 0.3 V (TI datasheet, absolute maximum ratings). If the preamp swings to its ±12 V rails, R2 keeps the current into the chip's input clamp to 1.3–2.4 mA (its limit is 10 mA). Gain error: 0.02 % on the ±6.144 V range, 0.66 % on the ±0.256 V range.

file:///tmp/claude-1000/-home-possum/72d223ad-2d6d-42c2-b6c6-65dd75786906/scratchpad/readme.html | 2/5

R3 (100k) pull-down on D8. A TRIG IN with nothing connected now reads LOW instead of picking up noise and giving false triggers.
Pin-1 triangles and "which way round" text on both sockets. Both breakouts fit in their sockets rotated 180°. For the MCP4725 that puts 5 V on its GND pin. Now the MCP4725 outline is the real 15.2 × 15.2 mm board.
Firmware and BOM fixes. dac.begin(0x60) (the library default is 0x62), and the BOM no longer orders the new two-row ADS1115 board that doesn't fit.

## Before you order: three things to check by hand

1. Which ADS1115 board do you have? Use the one from the class kit; do not order a new one. This shield fits the original Adafruit board with one row of 10 pins (VDD GND SCL SDA ADDR ALRT A0 A1 A2 A3). Adafruit now sells a newer STEMMA QT version (two rows of 6, "VIN" instead of "VDD") under the same product number 1085, and it does not fit. Your team's self-test sketch says "VDD", so you probably have the original, but count the pins.
2. Print fab/print_1to1_top.pdf at 100 % and lay the UNO and both breakouts on it. The header holes must line up with the UNO's pins and with each breakout's pins.
3. Height over the UNO's ATmega chip. D1, D2, C1, the ADS1115 socket and J4 all sit above it. Lying the parts flat and trimming the leads flush should clear it, but this has not been verified against a drawing: check it with the real UNO before soldering everything down.

## Parts (full list in BOM.csv )

Ref | Part | Where
U1 | Adafruit ADS1115 breakout (original, 1×10), from the class kit | plugs into a 1×10 female header (Sullins PPTC101LFBN-RC, Digi-Key S7008-ND). Don't order 1528-1085-ND: that is the new two-row board
U2 | SparkFun MCP4725 breakout BOB-12918 | plugs into a 1×6 female header (PPTC061LFBN-RC, S7004-ND). Retired at SparkFun, still at Digi-Key 1568-1047-ND
J1, J2, J3 | Phoenix 1984617 screw terminals, 3.5 mm | Digi-Key 277-1721-ND
J4 | 1×4 female header for the spare inputs | S7002-ND
R1 | 1k ¼ W resistor on the trigger | 1.0KQBK-ND
R2 | 4k7 ¼ W resistor in series with SIGNAL IN | 4.7KQBK-ND
R3 | 100k ¼ W pull-down on D8, mounted standing up | 100KQBK-ND
C1 | 100 nF 50 V X7R disc, 2.5 mm lead pitch (not Y5V: BC1160-ND is the wrong one) | BC1084CT-ND
D1, D2 | 1N4148 signal diodes (DO-35) | 1N4148FS-ND
— | UNO stacking headers | Adafruit 85 (legs just clear the USB jack)
file:///tmp/claude-1000/-home-possum/72d223ad-2d6d-42c2-b6c6-65dd75786906/scratchpad/readme.html | 3/5

No other parts. Both breakouts already carry the I²C pull-ups: the ADS1115 board has 10k on SDA and on SCL (hard-wired), the MCP4725 board has 4.7k on each through jumper SJ1 (closed by a trace from the factory). In parallel that is 3.2k per line, about 2.9k once the Arduino's own internal pull-ups are counted, which draws 1.6 mA at the low level against the 3 mA an I²C device must sink. The minimum sensible value here is about 1.5k, so this is fine and the shield adds no pull-ups of its own. If you ever chain more I²C boards onto this one, each brings its own pull-ups and the total drops: cut SJ1 on the MCP4725 board to take its 4.7k pair off the bus. The ADS1115 breakout also pulls ALRT (D2) up with 10k.

## Ordering and building

1. JLCPCB: upload fab/mie1001_daq_simple_gerbers.zip , 2 layers, 1.6 mm, HASL is fine. No assembly.
2. Solder, lowest parts first: D1, D2 (lying flat, stripe towards the K on the board), R1 and R2 (lying flat), C1, R3 (standing up, body on the circle), then the female headers (keep them straight: plug the breakout in while soldering), the terminal blocks, and finally the stacking headers.
3. Trim every lead under the board flush. This is required, not optional. The ADS1115 socket and J4 sit right above the UNO's ATmega chip, and D1, D2 and C1 are in the same band. An untrimmed socket lead sticks out about 1.6 mm and a terminal pin about 2.9 mm. Check the clearance over the ATmega with the real boards before you solder everything down.
4. Plug the breakouts in component side up, matching the pin names on the breakout to the names on the shield: VDD on the left for the ADS1115, and OUT at the top (at the ▼) for the MCP4725. Rotated 180° the MCP4725 gets 5 V on its GND pin.

## Firmware notes

ADS1115 at 0x48, MCP4725 at 0x60. Libraries: Adafruit ADS1X15 and Adafruit MCP4725.
dac.begin(0x60) : the Adafruit_MCP4725 library defaults to 0x62, so a plain | dac.begin() | finds nothing.
ads.begin() | (0x48) is correct as is.
Read the signal on A0. | ads.setGain(GAIN_TWOTHIRDS) | gives ±6.144 V full scale. For a small signal turn the
gain up instead of adding an amplifier: | GAIN_SIXTEEN | gives ±0.256 V full scale and ~7.8 µV steps.
The input is filtered at 339 Hz (R2 with C1), so the board cannot follow anything faster. Leave C1 out if you need the bandwidth.
For 50 Hz mains hum, use the ADC, not the filter. Set a low data rate
( ads.setDataRate(RATE_ADS1115_8SPS) ), whose internal averaging window rejects mains, or average a batch of readings in the sketch. C1 barely touches 50 Hz.
J4's spare inputs (A1–A3) have no resistor, clamp or filter. They go straight to the chip. Keep them under 0–VDD, and tie them to GND if you don't use them.
The useful input range is 0 V to VDD (the USB 5 V, often only 4.8 V). This board expects a voltage from Team 3's preamp, not the raw detector current. R2 protects the chip from a preamp that overshoots, but readings above VDD are not valid.
The MCP4725 powers up at mid-scale (2.5 V on QPS OUT). Write 0 to its EEPROM once.
Trigger in: pinMode(8, INPUT) , active HIGH. R3 holds D8 low when nothing is connected. Use 5 V logic if you can: the ATmega needs 3.0 V for a HIGH, so 3.3 V logic has only 0.3 V to spare. R1 limits the current if the trigger goes a little above 5 V.
file:///tmp/claude-1000/-home-possum/72d223ad-2d6d-42c2-b6c6-65dd75786906/scratchpad/readme.html | 4/5

ALRT goes to UNO pin 2: | pinMode(2, INPUT) | is enough, the breakout has the pull-up. (Careful reading the
board: the silkscreen "D2" next to C1 is the *diode* D2, not the UNO's pin 2.)

## Compared with the full board ( ../mie1001_daq_board , rev E)

This one has no electrometer amplifier and no guard ring: it digitises a voltage that someone else has already made. Since rev C it does have basic input protection (R2 with D1/D2) and a 339 Hz filter (R2 with C1), but nothing that can measure a current. That is exactly what the class breakouts are for, and it is much easier to build and debug. For picoamp detector currents, use the full board.

## Files

generate_schematic.py | and | generate_pcb.py | generate everything (the PCB script reuses the UNO geometry
and the router of the full board); | ./build.sh | rebuilds and re-runs all checks. The possum and the prayer to the
machine gods are in | generate_pcb.py , | possum() .
file:///tmp/claude-1000/-home-possum/72d223ad-2d6d-42c2-b6c6-65dd75786906/scratchpad/readme.html | 5/5

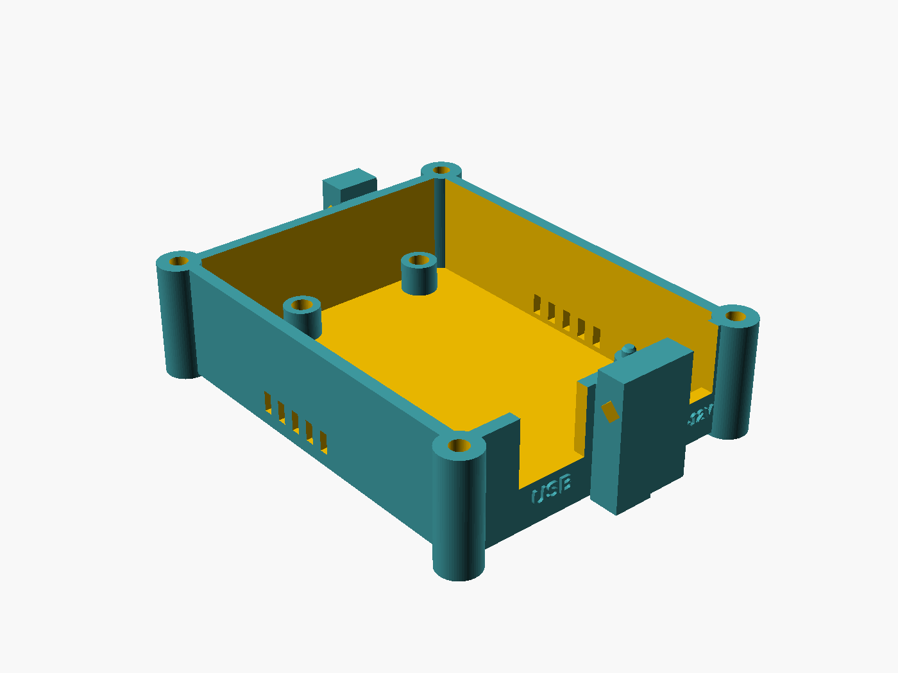
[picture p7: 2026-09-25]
hardware/enclosure/renders/base_left.png

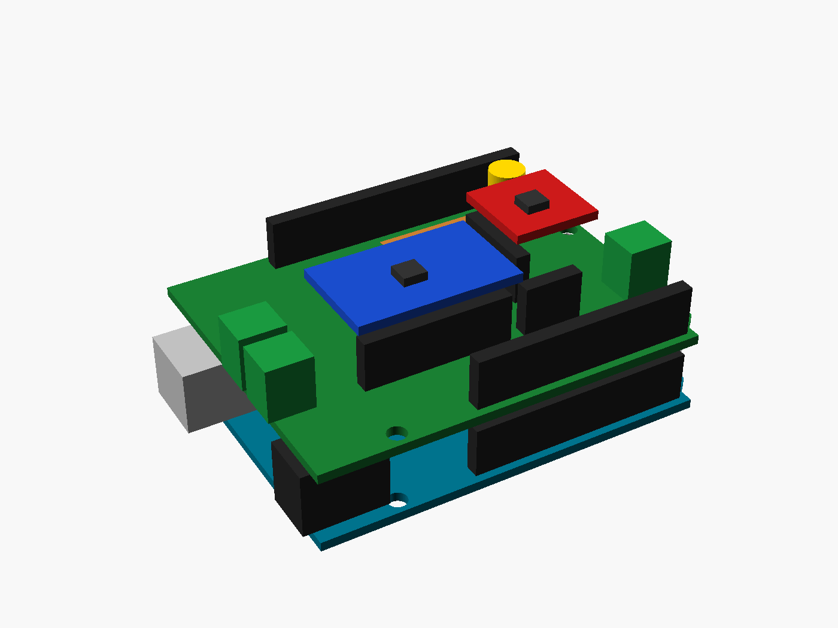
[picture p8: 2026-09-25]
hardware/enclosure/renders/boards_only.png

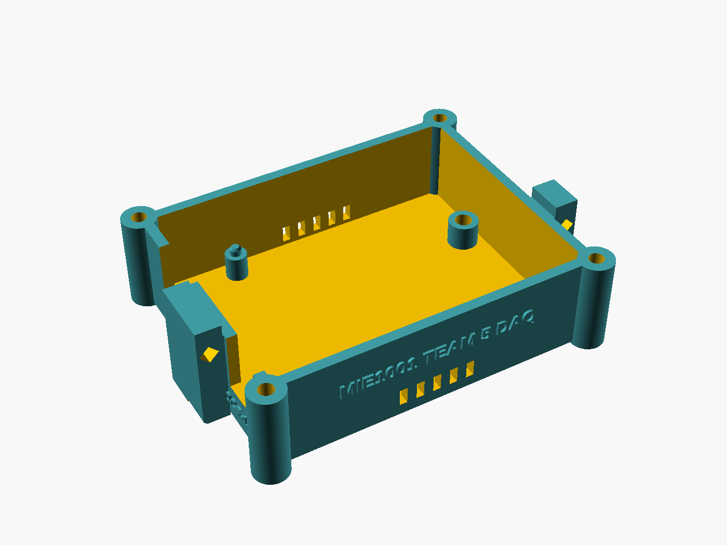
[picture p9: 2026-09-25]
hardware/enclosure/renders/base.png

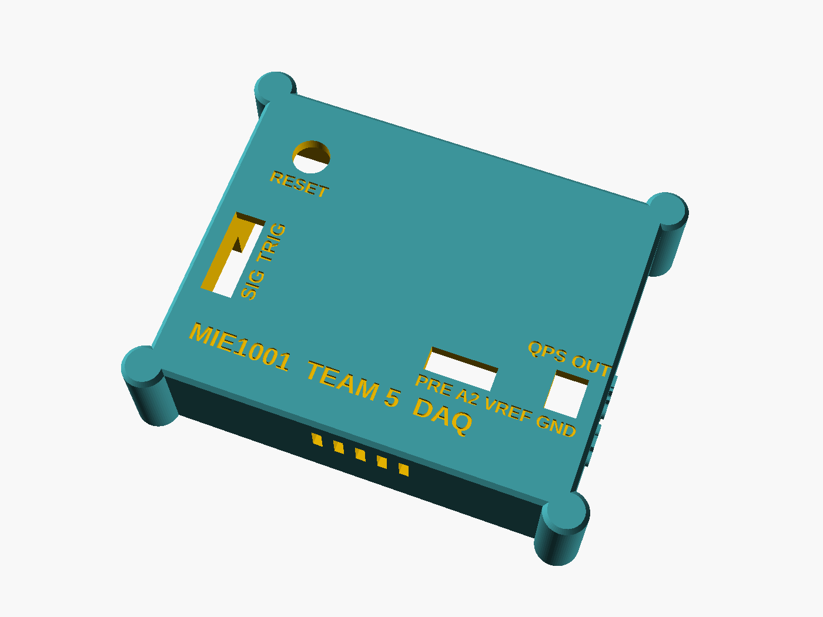
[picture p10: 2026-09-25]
hardware/enclosure/renders/lid_top.png

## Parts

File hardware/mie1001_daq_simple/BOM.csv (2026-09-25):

Qty | References | Value | Footprint | Manufacturer | MPN | Digi-Key P/N | LCSC | Note
1 | ARD1 | Arduino UNO R3 SMD (ATmega328P TQFP-32) | Module:Arduino_UNO_R3 | Arduino or compatible | UNO R3 SMD CH340 clone (marked V1888); A000073 is the official SMD edition | do not order: use your own board
1 | C1 | 100 nF 50 V X7R ceramic | Capacitor_THT:C_Disc_D5.0mm_W2.5mm_P2.50mm | Vishay Beyschlag/Draloric/BC Components | K104K15X7RF5TL2 | BC1084CT-ND |  | Filter cap at the ADS1115 input, 2.5 mm lead pitch. With R2 (4.7 kOhm) it is a single-pole low-pass at 339 Hz, and it supplies the charge the ADC's switched-capacitor input needs each sample. It does NOT remove 50 Hz hum (only 1.1 % at 50 Hz): use a low data rate or averaging for that. Must be X7R or C0G, NOT Y5V (Digi-Key BC1160-ND is the Y5V version: wrong part).
1 | C2 | 10pF C0G 50V 0603 | Capacitor_SMD:C_0603_1608Metric | Samsung Electro-Mechanics | CL10C100JB8NNNC | 1276-1027-1-ND | C1634 | C0G/NP0 only. MUST be fitted: without it the preamp oscillates with the cable capacitance. With R6 it sets a 159 Hz bandwidth.
2 | C3, C7 | 100nF X7R 50V 0603 | Capacitor_SMD:C_0603_1608Metric | Wurth Elektronik | 885012206095 | 732-8013-1-ND | C14663
1 | C4 | 10uF X5R 25V 0805 | Capacitor_SMD:C_0805_2012Metric | Taiyo Yuden | TMK212BBJ106KGHT | 587-4334-1-ND | C15850
2 | C5, C6 | 1uF X5R 25V 0603 | Capacitor_SMD:C_0603_1608Metric | Samsung Electro-Mechanics | CL10A105KA8NNNC | 1276-1102-1-ND | C5673 | VREF output capacitor (25 V is plenty at 2.5 V). With R11: 159 Hz anti-alias filter before ADS1115 A1.
2 | CR1, CR2 | 1N4148 | Diode_THT:D_DO-35_SOD27_P7.62mm_Horizontal | onsemi | 1N4148 | 1N4148FS-ND |  | Diverts most of the current to +5 V if the input goes high. R2 is what keeps the ADC inside its 10 mA limit. Mind the stripe: cathode (striped end) to +5V. Leakage 25 nA max adds up to 117 uV of offset through R2. Same, to GND, if the input goes below 0 V. Mind the stripe: cathode (striped end) to the signal.
1 | CR3 | BAV199LT1G | Package_TO_SOT_SMD:SOT-23 | onsemi | BAV199LT1G | BAV199LT1GOSCT-ND | C145516 | Clamp tied to VREF on both ends: 0 V bias means near-zero leakage into the pA node. Do not substitute a switching diode.
1 | J1 | Signal in | TerminalBlock_Phoenix:TerminalBlock_Phoenix_PT-1,5-2-3.5-H_1x02_P3.50mm_Horizontal | Phoenix Contact | 1984617 | 277-1721-ND
1 | J2 | QPS out | TerminalBlock_Phoenix:TerminalBlock_Phoenix_PT-1,5-2-3.5-H_1x02_P3.50mm_Horizontal | Phoenix Contact | 1984617 | 277-1721-ND
1 | J3 | Trigger in | TerminalBlock_Phoenix:TerminalBlock_Phoenix_PT-1,5-2-3.5-H_1x02_P3.50mm_Horizontal | Phoenix Contact | 1984617 | 277-1721-ND
1 | J4 | Spare ADC in | Connector_PinSocket_2.54mm:PinSocket_1x04_P2.54mm_Vertical | Sullins Connector Solutions | PPTC041LFBN-RC | S7002-ND
1 | J5 | Detector in, SMA jack vertical | Connector_Coaxial:SMA_Amphenol_132134_Vertical | Amphenol RF | 132134 | ACX1230-ND |  | Faraday cup input. SMA with a PTFE insulator; use a BNC-female to SMA-male adapter for a BNC cable. Hand-solder. The centre pin sits in the VREF guard: keep it clean.
1 | R1 | 1 kOhm 0.25 W | Resistor_THT:R_Axial_DIN0207_L6.3mm_D2.5mm_P10.16mm_Horizontal | YAGEO | CFR-25JB-52-1K | 1.0KQBK-ND |  | Series resistor on the trigger input: limits the current if the trigger is driven a little above 5 V.
1 | R2 | 4.7 kOhm 0.25 W | Resistor_THT:R_Axial_DIN0207_L6.3mm_D2.5mm_P10.16mm_Horizontal | YAGEO | CFR-25JB-52-4K7 | 13-CFR-25JB-52-4K7-ND |  | Series resistor on SIGNAL IN: this is the part that actually protects the ADC, limiting the input current to 1.3-2.4 mA at +/-12 V against its 10 mA absolute maximum. Gain error from the ADS1115 input impedance: under 0.1 % at +/-6.144 V, 0.66 % at +/-0.256 V.
1 | R3 | 100 kOhm 0.25 W | Resistor_THT:R_Axial_DIN0207_L6.3mm_D2.5mm_P2.54mm_Vertical | YAGEO | CFR-25JB-52-100K | 13-CFR-25JB-52-100K-ND |  | Pull-down on D8: an unconnected TRIG IN reads LOW instead of floating.
1 | R4 | 10 kOhm 0.25 W | Resistor_THT:R_Axial_DIN0207_L6.3mm_D2.5mm_P2.54mm_Vertical | YAGEO | CFR-25JB-52-10K | 13-CFR-25JB-52-10K-ND |  | Surge resistor at the input: limits the current into CR3 if the cup cable carries a discharge. Through-hole, mounted standing up; hand-solder. 10 uV drop per nA.
3 | R5, R7, R11 | 1k 1% 0603 | Resistor_SMD:R_0603_1608Metric | YAGEO | RC0603FR-071KL | 311-1.00KHRCT-ND | C21190 | Protects the LMP7721 IN+ from spikes on VREF; carries only fA.
1 | R6 | 100M 1% 1206 | Resistor_SMD:R_1206_3216Metric | Stackpole Electronics Inc | HVCB1206FKC100M | HVCB1206FKC100MCT-ND | C59781 | 100 MOhm feedback: 1 nA -> 0.1 V. Guard the pads, keep them clean, no flux residue. Must stay a high-value low-leakage 1 % part: do not substitute a general-purpose 1206. (The LCSC column is only for the optional JLC route: Uniroyal 1206W4F1006T5E.)
2 | R8, R9 | 100k 1% 0603 | Resistor_SMD:R_0603_1608Metric | YAGEO | RC0603FR-07100KL | 311-100KHRCT-ND | C25803 | Rev E: 100k/100k (was 10k/10k). With C4 10 uF the divider noise corner is 0.32 Hz, so 50 Hz ripple on the USB 5 V is attenuated ~160x before U4A. MCP6002 input bias ~1 pA: no error.
1 | R10 | 100R 1% 0603 | Resistor_SMD:R_0603_1608Metric | YAGEO | RC0603FR-07100RL | 311-100HRCT-ND | C22775 | Isolation resistor so the MCP6002 VREF buffer can drive C5.
1 | U1 | Adafruit ADS1115 breakout (original, 1x10) | Connector_PinSocket_2.54mm:PinSocket_1x10_P2.54mm_Vertical | Adafruit | 1085 (ORIGINAL 1x10 version, from the class kit) | do not order |  | Use the board from the class kit. The footprint is a 1x10 female header (PPTC101LFBN-RC) and fits only the ORIGINAL Adafruit board (one row: VDD GND SCL SDA ADDR ALRT A0-A3). What Digi-Key/Adafruit sell today as 1085 (1528-1085-ND) is the STEMMA QT version with two rows of 6: it does NOT fit.
1 | U2 | SparkFun MCP4725 breakout | Connector_PinSocket_2.54mm:PinSocket_1x06_P2.54mm_Vertical | SparkFun Electronics | 12918 | 1568-12918-ND |  | SparkFun BOB-12918. The footprint is a 1x6 female header (PPTC061LFBN-RC). Pull-ups ON (default), A0 jumper to GND (default) -> address 0x60. Retired at SparkFun but Active at Digi-Key (656 in stock on 2026-09-25). If it runs out, use the class-kit board: no pin-compatible replacement exists (Adafruit's MCP4725 breakout has a different pin order).
1 | U3 | LMP7721MA/NOPB | Package_SO:SOIC-8_3.9x4.9mm_P1.27mm | Texas Instruments | LMP7721MA/NOPB | LMP7721MA/NOPB-ND | C124427 | Electrometer preamp (3 fA typical input bias). Guard ring (VREF) on both layers around pins 1/8 and the feedback parts, closed under the chip between pins 2 and 7; the guard copper is left free of solder mask (rev E), tracks and the gaps next to them stay masked. Clean flux off after soldering.
1 | U4 | MCP6002-I/SN | Package_SO:SOIC-8_3.9x4.9mm_P1.27mm | Microchip Technology | MCP6002-I/SN | MCP6002-I/SN-ND | C116706 | Unit A buffers the 2.5 V reference (VREF); unit B is unused, wired as a follower.
1 | X1 | Female header 1x10 for U1 | (on U1/U2 footprint) | Sullins Connector Solutions | PPTC101LFBN-RC | S7008-ND
1 | X2 | Female header 1x6 for U2 | (on U1/U2 footprint) | Sullins Connector Solutions | PPTC061LFBN-RC | S7004-ND
1 | - | Stacking header set for UNO R3 (1x10, 2x 1x8, 1x6) |  | Adafruit Industries LLC | 85 | 1528-1074-ND |  | Adafruit product 85, Arduino R3 shield stacking headers; 10.5 mm legs clear the UNO's USB-B jack.

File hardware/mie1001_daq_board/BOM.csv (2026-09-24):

Qty | References | Value | Footprint | Manufacturer | MPN | Digi-Key P/N | LCSC | Note
1 | A1 | Arduino UNO R3 | Module:Arduino_UNO_R3 | Arduino | A000066 | 1050-1024-ND
1 | C1 | 10pF C0G 50V 0603 | Capacitor_SMD:C_0603_1608Metric | Murata | GRM1885C1H100JA01D | 490-1403-1-ND | C1634 | MUST be fitted. TIA stability needs Cf >= sqrt(Cin/(2*pi*Rf*GBW)); with ~100 pF of cable, Rf = 2M2 and the LMP7721's 17 MHz GBW that is ~0.65 pF, so 10 pF has wide margin (sets a 7.2 kHz / 159 Hz pole).
3 | C2, C9, C10 | 1uF X5R 50V 0603 | Capacitor_SMD:C_0603_1608Metric | Samsung | CL10A105KB8NNNC | 1276-1860-1-ND | C15849 | Any 1 uF >=16 V X5R/X7R 0603 works; confirm JLCPCB stock of C15849 when ordering.
2 | C3, C7 | 10uF X5R 25V 0805 | Capacitor_SMD:C_0805_2012Metric | Samsung | CL21A106KAYNNNE | 1276-2891-1-ND | C15850
4 | C4, C5, C6, C8 | 100nF X7R 50V 0603 | Capacitor_SMD:C_0603_1608Metric | Samsung | CL10B104KB8NNNC | 1276-1000-1-ND | C14663
1 | D1 | BAV199LT1G | Package_TO_SOT_SMD:SOT-23 | onsemi | BAV199LT1G | BAV199LT1GOSCT-ND | C145516 | Tied to VREF, not the rails: 0 V bias means near-zero leakage into the pA node (20-50 pA per diode at 2.5 V reverse).
1 | J1 | Detector in, BNC | Connector_Coaxial:BNC_Amphenol_031-6575_Horizontal | Amphenol RF | 031-6575 | ARF2111-ND
1 | J2 | QPS mass cmd out | TerminalBlock_Phoenix:TerminalBlock_Phoenix_PT-1,5-2-3.5-H_1x02_P3.50mm_Horizontal | Phoenix Contact | 1984617 | 277-1721-ND
1 | J3 | VREF / AIN3 / GND | Connector_PinHeader_2.54mm:PinHeader_1x03_P2.54mm_Vertical | Sullins | PRPC040SAAN-RC | S1011EC-40-ND
1 | J4 | Trigger in | TerminalBlock_Phoenix:TerminalBlock_Phoenix_PT-1,5-2-3.5-H_1x02_P3.50mm_Horizontal | Phoenix Contact | 1984617 | 277-1721-ND
1 | JP1 | TIA range select | Connector_PinHeader_2.54mm:PinHeader_1x03_P2.54mm_Vertical | Sullins | PRPC040SAAN-RC | S1011EC-40-ND
1 | R1 | 2M2 1% 0603 | Resistor_SMD:R_0603_1608Metric | Yageo | RC0603FR-072M2L | YAG3329CT-ND | C22938
1 | R2 | 100M 1% 1206 | Resistor_SMD:R_1206_3216Metric | Stackpole | HVCB1206FKC100M | HVCB1206FKC100MCT-ND | C59781 | High-value TIA feedback: guard the pads, keep them clean, no flux residue. JLC/LCSC has no HVCB stock: use Uniroyal 1206W4F1006T5E (C59781), 1% +-100 ppm/C.
6 | R3, R4, R9, R13, R16, R17 | 1k 1% 0603 | Resistor_SMD:R_0603_1608Metric | Yageo | RC0603FR-071KL | 311-1.00KHRCT-ND | C21190 | Protects the LMP7721 IN+ from transients on VREF; carries only fA.
2 | R5, R6 | 4k7 1% 0603 | Resistor_SMD:R_0603_1608Metric | Yageo | RC0603FR-074K7L | 311-4.70KHRCT-ND | C23162
4 | R7, R8, R10, R11 | 10k 1% 0603 | Resistor_SMD:R_0603_1608Metric | Yageo | RC0603FR-0710KL | 311-10.0KHRCT-ND | C25804 | ALERT/RDY is open-drain - this pull-up is required
2 | R12, R15 | 100R 1% 0603 | Resistor_SMD:R_0603_1608Metric | Yageo | RC0603FR-07100RL | 311-100HRCT-ND | C22775 | Isolation resistor: MCP6002 driving >100 pF of cable needs Riso (DS20001733L section 4.3). Isolation resistor so the MCP6002 VREF buffer can drive C9.
1 | R14 | 10k 1% 0603 anti-surge | Resistor_SMD:R_0603_1608Metric | Panasonic | ERJ-PA3F1002V | P10KBYCT-ND |  | Series protection at the BNC: anti-surge (pulse-rated, AEC-Q200) 0603, limits the current into D1. 10 uV drop per nA. HAND-SOLDER from the Digi-Key order (not in the JLC assembly files).
1 | U1 | MCP4725A0T-E/CH | Package_TO_SOT_SMD:SOT-23-6 | Microchip | MCP4725A0T-E/CH | MCP4725A0T-E/CHCT-ND | C144198
1 | U2 | ADS1115IDGSR | Package_SO:MSOP-10_3x3mm_P0.5mm | Texas Instruments | ADS1115IDGSR | 296-38849-1-ND | C37593
1 | U3 | MCP6002-I/SN | Package_SO:SOIC-8_3.9x4.9mm_P1.27mm | Microchip | MCP6002-I/SN | MCP6002-I/SN-ND | C116706
1 | U4 | LMP7721MA/NOPB | Package_SO:SOIC-8_3.9x4.9mm_P1.27mm | Texas Instruments | LMP7721MA/NOPB | LMP7721MA/NOPB-ND | C124427 | Electrometer TIA. Guard ring (VREF) on both layers around pins 1/8 and the feedback parts, no solder mask there. Clean flux off after soldering.

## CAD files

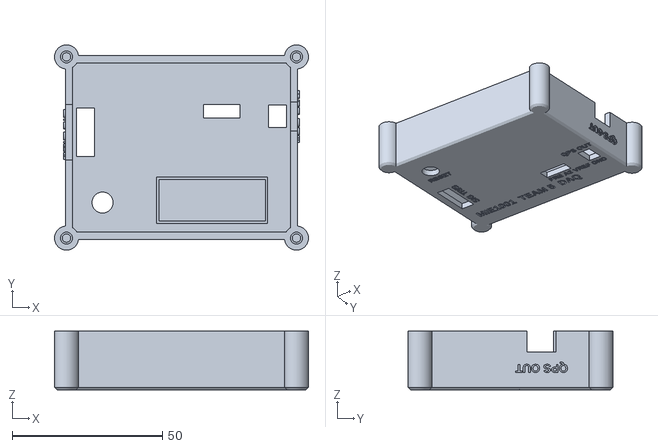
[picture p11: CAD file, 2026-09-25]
hardware/enclosure/stl/daq_lid.stl
84.6 x 68.3 x 19.5

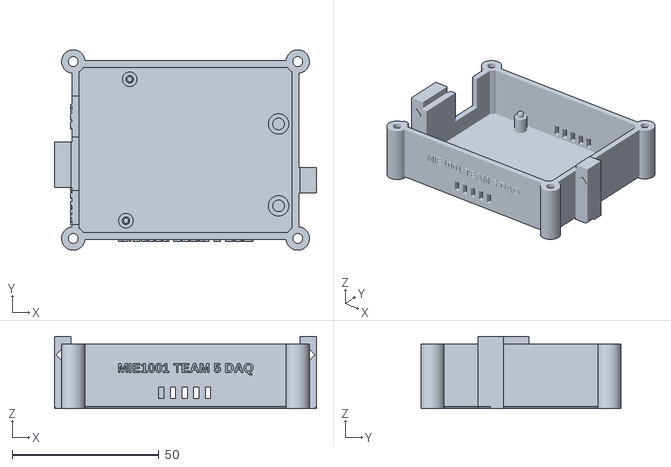
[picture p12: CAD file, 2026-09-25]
hardware/enclosure/stl/daq_base.stl
89.4 x 68.3 x 24.7

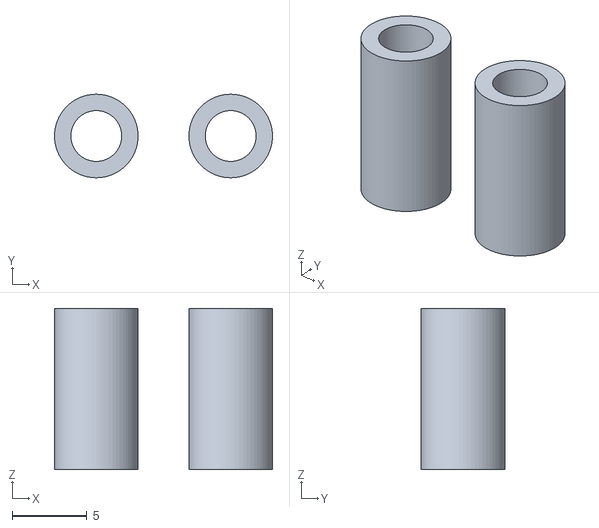
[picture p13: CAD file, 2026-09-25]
hardware/enclosure/stl/daq_spacer_x2.stl
14.6 x 5.60 x 10.8

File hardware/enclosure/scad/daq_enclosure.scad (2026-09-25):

// =====================================================================================
//  MIE1001 Team 5 DAQ enclosure  --  Arduino UNO R3 (SMD CH340 clone) + mie1001_daq_simple shield
//  Transparent PETG, 0.4 mm nozzle, no supports.  Two printed parts: BASE tray + LID.
//
//  Render one part:   openscad -D 'part="base"' -o ../stl/daq_base.stl daq_enclosure.scad
//                     openscad -D 'part="lid"'  -o ../stl/daq_lid.stl  daq_enclosure.scad
//  part = "assembly" | "exploded" | "base" | "lid" | "base_print" | "lid_print" | "report"
//
//  Frame (mm): origin = lower-left corner of the UNO seen from the top (USB-B and DC jacks on the
//  LEFT edge, power/analog header at the FRONT (y = 2.54), digital header at the BACK (y = 50.8)),
//  z = 0 on the table.  Connector positions of the shield come from pcb_positions.scad, which is
//  generated from the KiCad board by ../tools/make_positions.py -- do not type them in here.
// =====================================================================================
include <pcb_positions.scad>

part = "assembly";
$fn = 64;

// ---------------------------------------------------------------- print / fit
wall      = 2.4;     // side walls: 6 perimeters of 0.4 mm -> solid and clear
floor_t   = 2.4;     // base floor
lid_t     = 2.4;     // lid top plate
fit       = 0.3;     // PETG clearance on every sliding / plugging fit
chamfer   = 0.8;     // 45 deg chamfer on the bed edges (no elephant's foot, no overhang)
corner_r  = 3.0;     // vertical corner radius of the shell
label_d   = 0.6;     // text depth (engraved on the lid top, embossed on the walls)

// ---------------------------------------------------------------- the boards (measure yours!)
uno_l      = 68.58;  // UNO outline (A000066): 2.70 x 2.10 in
uno_w      = 53.34;
pcb_t      = 1.6;
standoff_h = 6.0;    // floor -> underside of the UNO (clears the UNO's through-hole solder tails)
jack_h     = 11.0;   // USB-B shell / DC jack height above the UNO top   [ASSUMED, measure the clone]
stack_gap  = 11.0;   // UNO top -> shield underside (shield rests on the USB-B shell, stacking hdr)
brk_h      = 14.5;   // highest point of a plugged breakout above the shield top
                     //   = 8.5 socket + 2.5 pin spacer + 1.6 PCB + ~1.9 parts / pin tips
hdr_h      = 8.5;    // stacking-header / socket bodies above the shield top
term_h     = 9.2;    // Phoenix PT 1,5/2-3,5-H body height (KiCad 3D model bbox)
wire_z_rel = 3.9;    // wire-entry centre above the shield top          [ASSUMED from Phoenix drawing]
sma_h      = 10.2;   // Amphenol 132134 height above the shield          [ASSUMED]
lid_clear  = 2.0;    // breakouts -> lid ceiling

// jacks of the UNO (A000066 board-outline drawing, scaled; clones vary +-0.5 mm)
usb_y = 38.1;  usb_w = 12.0;  usb_over = 6.5;  usb_in = 9.7;   // centre y, width, overhang, depth on board
dc_y  = 7.0;   dc_w  = 9.2;   dc_over  = 1.6;  dc_in  = 12.7;
dc_cz = 6.4;                                                    // DC plug axis above the UNO top

// UNO mounting holes (A000066).  Screws only in the two right-hand holes (= shield H2, H3): the stack
// is clamped there through a spacer between the boards.  The two left holes get support pins with a
// locating peg: at (13.97, 2.54) an M3 head / spacer would hit the DC jack body (the A000066 drawing
// shows the hole partly under it), at (15.24, 50.8) it would hit the SCL header pin.
uno_holes  = [[66.04, 7.62], [66.04, 35.56]];       // M3 heat-set inserts
uno_pegs   = [[13.97, 2.54], [15.24, 50.80]];       // support pin + peg
boss_d     = 7.0;
peg_boss_d = 5.0;
spacer_od  = 5.6;   // printed spacer between UNO and shield at H2/H3 (round: clears the ICSP header)
insert_d   = 4.0;               // M3 x 5.7 heat-set insert (CNC-Kitchen type) -> 4.0 mm hole
insert_len = 6.5;

// ---------------------------------------------------------------- derived heights
uno_z0     = floor_t + standoff_h;          // UNO underside
uno_top    = uno_z0 + pcb_t;
shield_z0  = uno_top + stack_gap;
shield_top = shield_z0 + pcb_t;
z_split    = uno_top + jack_h + 1.0;        // base / lid parting plane: 1 mm above both jacks
z_ceil     = shield_top + brk_h + lid_clear;
z_top      = z_ceil + lid_t;
wire_z     = shield_top + wire_z_rel;

// ---------------------------------------------------------------- cavity & shell
cx = 2.0;  cy = 1.5;                        // board edge -> inner wall (x: terminals overhang ~1 mm)
xi0 = -cx;  xi1 = uno_l + cx;  yi0 = -cy;  yi1 = uno_w + cy;
xo0 = xi0 - wall;  xo1 = xi1 + wall;  yo0 = yi0 - wall;  yo1 = yi1 + wall;

// lid screws: 4 x M3 x 30 countersunk (ISO 10642) from below, into heat-set inserts in the lid
post_r   = 4.0;
post_off = 2.0;                              // post centre diagonal offset outside the cavity corner
posts = [[xi0 - post_off, yi0 - post_off], [xi1 + post_off, yi0 - post_off],
         [xi0 - post_off, yi1 + post_off], [xi1 + post_off, yi1 + post_off]];
lid_insert_depth = 10.0;                     // 5.7 insert + room for the screw tip

// ---------------------------------------------------------------- openings
// USB-B and DC: U-notches in the base wall, open at the parting plane (the stack drops in from above)
usb_notch = [usb_y - usb_w/2 - 1.0, usb_y + usb_w/2 + 1.0, uno_top - 1.0];   // y0, y1, z bottom
dc_notch  = [dc_y  - dc_w/2 - 1.2,  dc_y  + dc_w/2 + 1.2,  uno_top - 1.0];
// Wire slots for the screw terminals, open at the bottom edge of the lid wall
sigtrig_slot = [J1_crtyd[1] - 0.8, J3_crtyd[3] + 0.8, wire_z + 2.5];          // y0, y1, z top
qps_slot     = [J2_crtyd[1] - 0.8, J2_crtyd[3] + 0.8, wire_z + 2.5];
// screwdriver windows in the lid top over the terminal screws (whole block top, front part)
sigtrig_win = [J1_crtyd[0] + 0.8, J1_crtyd[1] + 0.3, J1_pads[0][0] + 1.6, J3_crtyd[3] - 0.3];
qps_win     = [J2_pads[0][0] - 1.6, J2_crtyd[1] + 0.3, J2_crtyd[2] - 0.8, J2_crtyd[3] - 0.3];
// J4 header: slot for 4 Dupont plugs
j4_slot = [J4_pads[0][0] - 1.27 - 1.0, J4_pads[0][1] - 1.27 - 1.0,
           J4_pads[3][0] + 1.27 + 1.0, J4_pads[0][1] + 1.27 + 1.0];
// Faraday cup coax
faraday_mode = "none";         // "none"       : plain box for the UNO + shield only, no Faraday-cup opening (current choice)
                               // "passthrough": the SMA(m)->BNC(f) adapter goes up through the lid
                               // "bulkhead"   : BNC bulkhead jack in the lid + short SMA pigtail
faraday_pass_d = 12.5;         // clears the adapter's BNC bayonet studs (11.6) and SMA nut (9.2)
bnc_bulk_d = 9.7;  bnc_bulk_flat = 8.9;   // D-hole for a 3/8-32 BNC bulkhead jack [check its datasheet]
tie_slot = [4.6, 2.0];         // cable-tie slots (x, y) next to the BNC: tie the cable to the lid
// reset: the UNO's button is under the shield -> optional 7 mm hole for a panel push button
//        wired to RESET + GND of the stacking header (see README)
reset_button = true;
reset_pos = [8.0, 45.0];  reset_d = 7.0;
// copper-tape patch over the preamp (inside of the lid ceiling): engraved outline as a guide
patch = [26.0, 36.5, 63.0, 52.0];  // x0 y0 x1 y1, covers guard_bbox + VREF buffer + output filter
// ventilation: inlet slots low in the base (front+back), outlet slots high in the lid front wall
vent_x = [26, 30, 34, 38, 42];  vent_w = 1.8;

// ---------------------------------------------------------------- colours for the renders
c_petg = [0.75, 0.9, 1.0, 0.35];
c_petg_solid = [0.55, 0.78, 0.95, 1.0];
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

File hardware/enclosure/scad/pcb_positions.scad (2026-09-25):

// GENERATED by tools/make_positions.py from the shield's .kicad_pcb -- do not edit by hand.
// Board frame: origin = UNO lower-left corner (jacks on the left), mm, seen from the top.

pcb_holes = [[13.97, 2.54], [66.04, 7.62], [66.04, 35.56]];  // shield M3 holes H1..H3
J1_pads = [[3.64, 18.94], [3.64, 15.44]];  // SIGNAL IN, wire entry faces -x
J3_pads = [[3.64, 27.74], [3.64, 24.24]];  // TRIG IN, wire entry faces -x
J2_pads = [[64.94, 14.54], [64.94, 18.04]];  // QPS OUT, wire entry faces +x
J4_pads = [[43.94, 14.54], [46.48, 14.54], [49.02, 14.54], [51.56, 14.54]];  // 1x4 socket PRE_OUT A2 VREF GND
U1_pads = [[15.94, 14.54], [18.48, 14.54], [21.02, 14.54], [23.56, 14.54], [26.1, 14.54], [28.64, 14.54], [31.18, 14.54], [33.72, 14.54], [36.26, 14.54], [38.8, 14.54]];  // ADS1115 1x10 socket
U2_pads = [[47.44, 35.54], [47.44, 33.0], [47.44, 30.46], [47.44, 27.92], [47.44, 25.38], [47.44, 22.84]];  // MCP4725 1x6 socket
J5_pos = [58.34, 43.54];  // SMA vertical centre pin
J1_crtyd = [-1.405, 13.145, 7.285, 21.235];  // courtyard [x0,y0,x1,y1]
J2_crtyd = [61.295, 12.245, 69.985, 20.335];  // courtyard [x0,y0,x1,y1]
J3_crtyd = [-1.405, 21.945, 7.285, 30.035];  // courtyard [x0,y0,x1,y1]
J5_crtyd = [54.125, 39.325, 62.555, 47.755];  // courtyard [x0,y0,x1,y1]
guard_bbox = [36.34, 38.84, 60.465, 48.14];  // guard top
usb_keepout = [0.0, 31.34, 10.54, 44.84];  // USB-B jack
icsp_keepout = [61.94, 23.94, 67.84, 32.14];  // ICSP header
dc_keepout = [0.0, 0.0, 11.94, 13.04];  // DC jack
ads_outline = [13.4, 12.51, 41.34, 29.78];  // ADS1115 board lying flat, 1.10 x 0.68 in
mcp_outline = [46.17, 21.57, 61.41, 36.81];  // MCP4725 board lying flat, 0.6 x 0.6 in

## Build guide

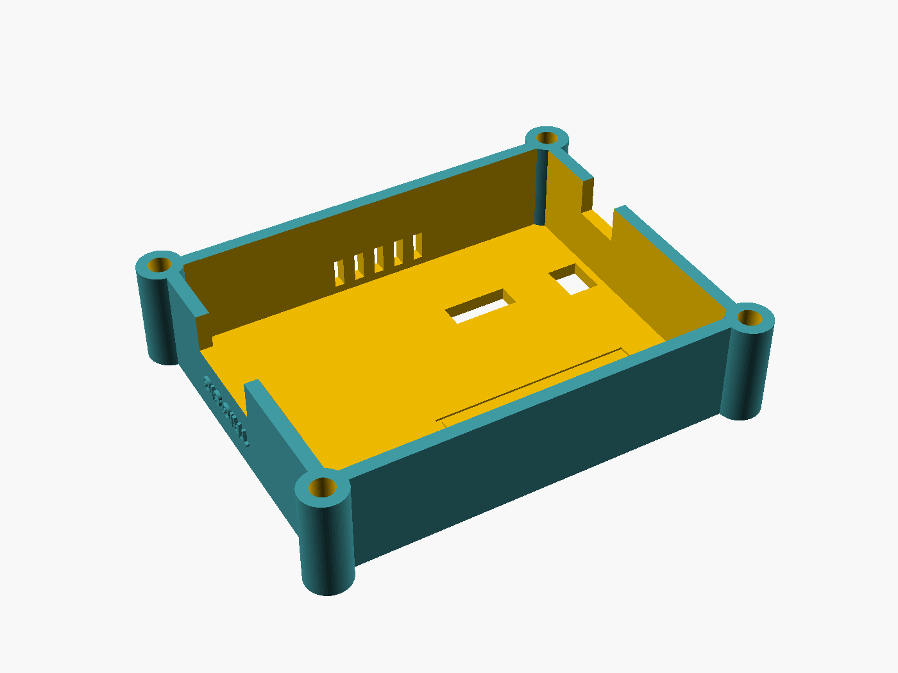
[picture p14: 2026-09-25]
hardware/enclosure/renders/lid_print.png

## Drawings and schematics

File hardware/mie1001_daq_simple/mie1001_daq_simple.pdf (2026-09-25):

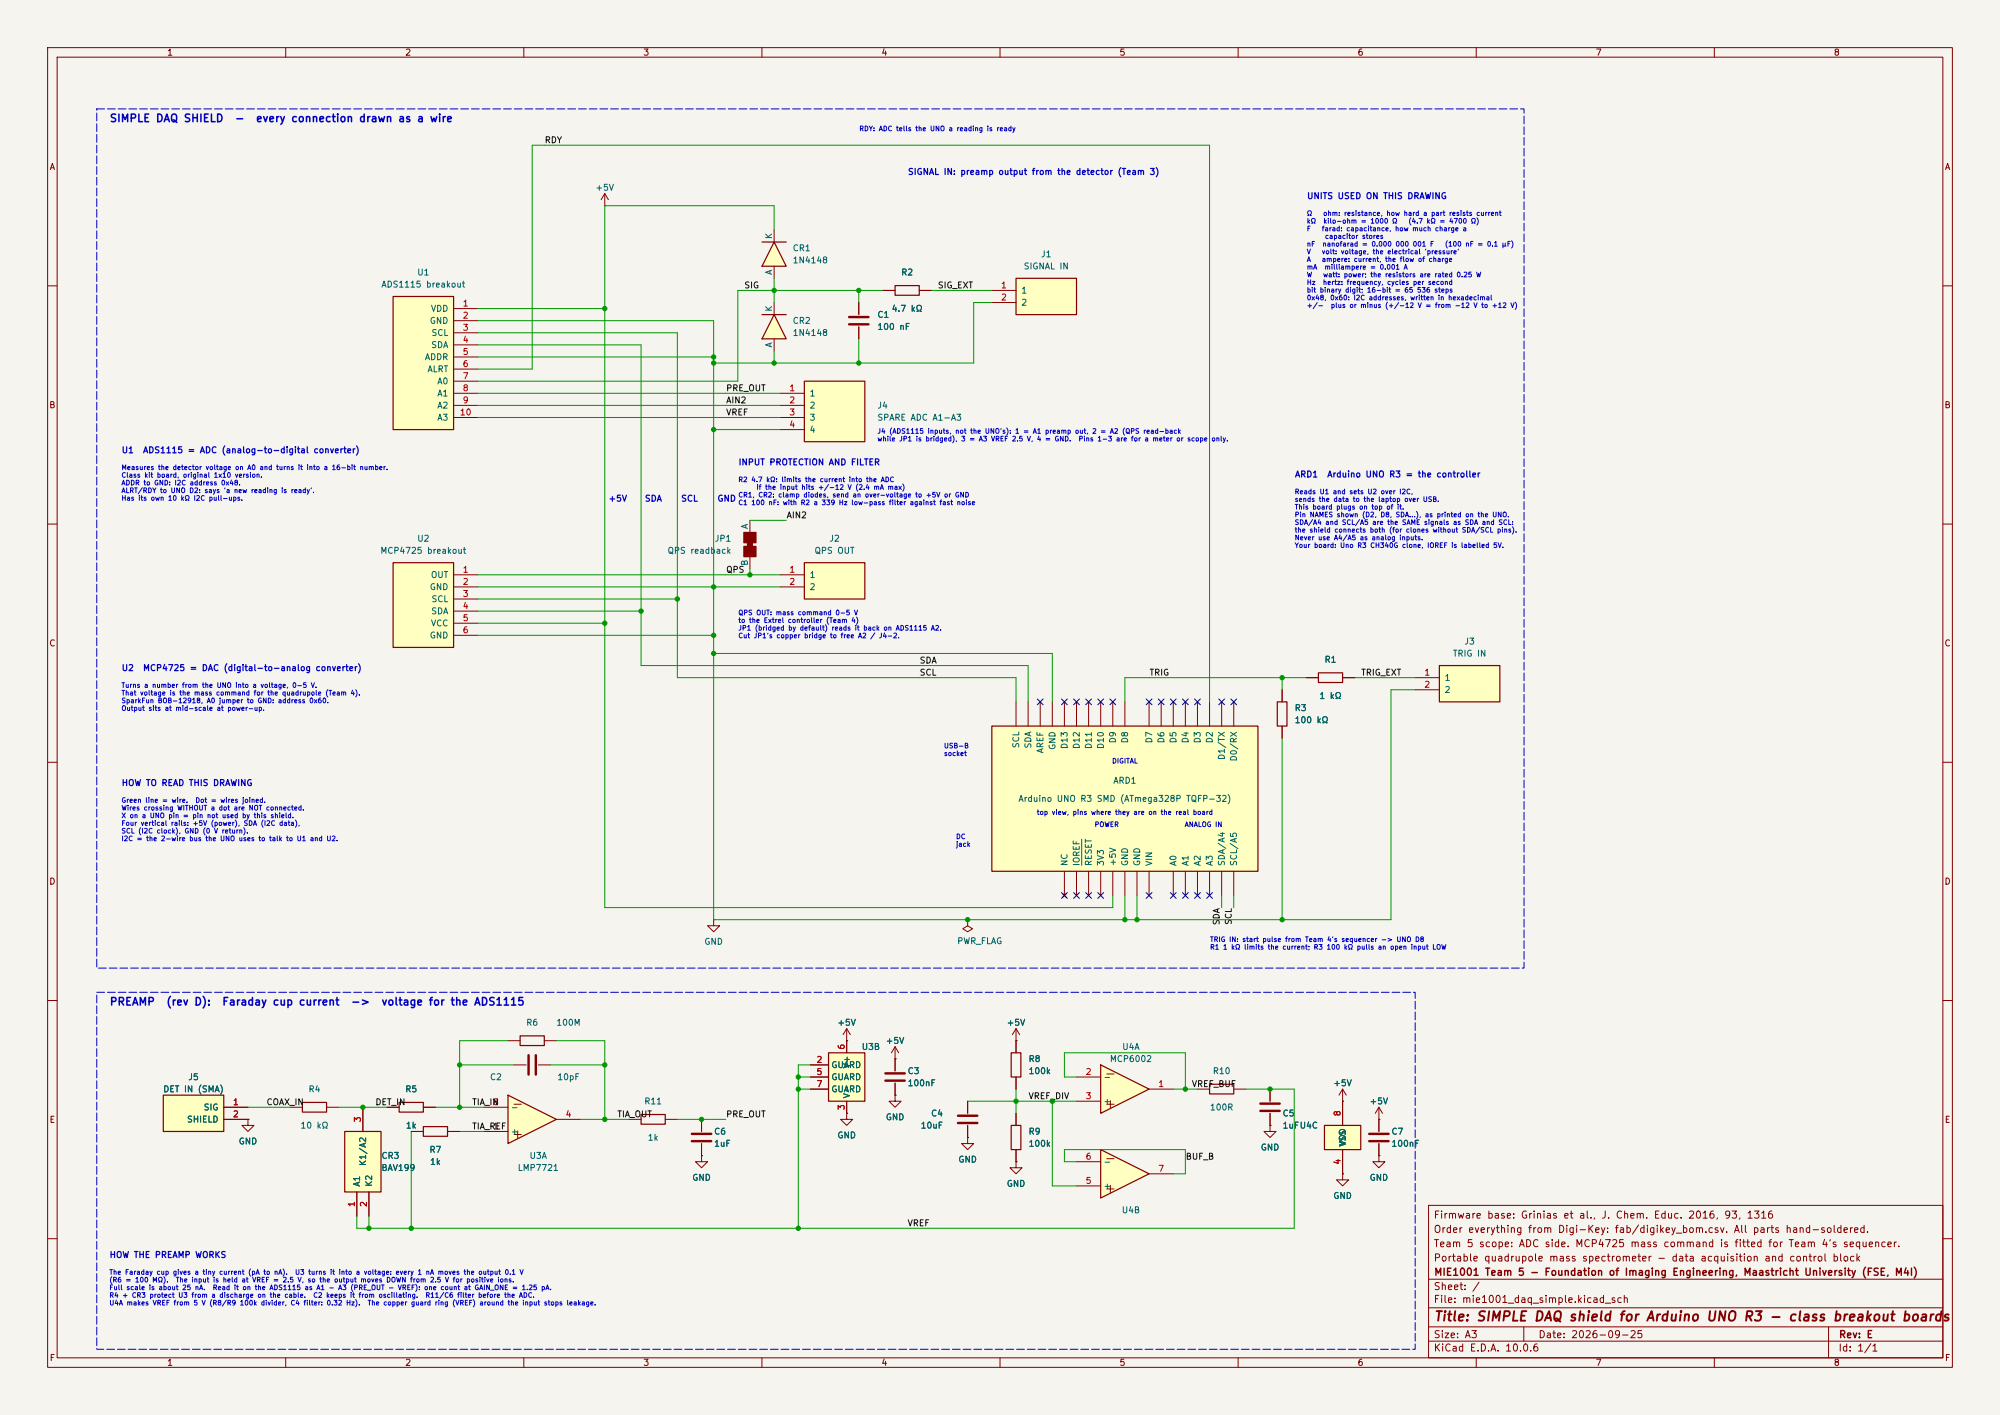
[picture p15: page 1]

RDY: ADC tells the UNO a reading is ready

SIGNAL IN: preamp output from the detector (Team 3)

Hz hertz: frequency, cycles per second
bit binary digit; 16-bit = 65 536 steps 0x48, 0x60: I2C addresses, written in hexadecimal +/- plus or minus (+/-12 V = from -12 V to +12 V) ARD1 Arduino UNO R3 = the controller Reads U1 and sets U2 over I2C, sends the data to the laptop over USB. This board plugs on top of it. Pin NAMES shown (D2, D8, SDA...), as printed on the UNO. SDA/A4 and SCL/A5 are the SAME signals as SDA and SCL: the shield connects both (for clones without SDA/SCL pins). Never use A4/A5 as analog inputs. Your board: Uno R3 CH340G clone, IOREF is labelled 5V.

VREF 3

socket U1 ADS1115 = ADC (analog-to-digital converter)

INPUT PROTECTION AND FILTER

R2 4.7 kΩ: limits the current into the ADC
if the input hits +/-12 V (2.4 mA max) CR1, CR2: clamp diodes, send an over-voltage to +5V or GND

C1 100 nF: with R2 a 339 Hz low-pass filter against fast noise QPS OUT: mass command 0-5 V

to the Extrel controller (Team 4) JP1 (bridged by default) reads it back on ADS1115 A2. Cut JP1's copper bridge to free A2 / J4-2. PREAMP (rev D): Faraday cup current -> voltage for the ADS1115

Green line = wire. Dot = wires joined. Wires crossing WITHOUT a dot are NOT connected. X on a UNO pin = pin not used by this shield. Four vertical rails: +5V (power), SDA (I2C data), SCL (I2C clock), GND (0 V return).

top view, pins where they are on the real board

I2C = the 2-wire bus the UNO uses to talk to U1 and U2. HOW THE PREAMP WORKS

TRIG IN: start pulse from Team 4's sequencer -> UNO D8 R1 1 kΩ limits the current; R3 100 kΩ pulls an open input LOW

Firmware base: Grinias et al., J. Chem. Educ. 2016, 93, 1316 +5V GND

Order everything from Digi-Key: fab/digikey_bom.csv. All parts hand-soldered.
Team 5 scope: ADC side. MCP4725 mass command is fitted for Team 4's sequencer.
Portable quadrupole mass spectrometer - data acquisition and control block
MIE1001 Team 5 - Foundation of Imaging Engineering, Maastricht University (FSE, M4I)
Sheet: /
File: mie1001_daq_simple.kicad_sch
Title: SIMPLE DAQ shield for Arduino UNO R3 - class breakout boards

The Faraday cup gives a tiny current (pA to nA). U3 turns it into a voltage: every 1 nA moves the output 0.1 V
(R6 = 100 MΩ). The input is held at VREF = 2.5 V, so the output moves DOWN from 2.5 V for positive ions. Full scale is about 25 nA. Read it on the ADS1115 as A1 - A3 (PRE_OUT - VREF): one count at GAIN_ONE = 1.25 pA. R4 + CR3 protect U3 from a discharge on the cable. C2 keeps it from oscillating. R11/C6 filter before the ADC. U4A makes VREF from 5 V (R8/R9 100k divider, C4 filter: 0.32 Hz). The copper guard ring (VREF) around the input stops leakage.

Size: A3 | Rev: E | F Date: 2026-09-25
KiCad E.D.A. 10.0.6 | Id: 1/1

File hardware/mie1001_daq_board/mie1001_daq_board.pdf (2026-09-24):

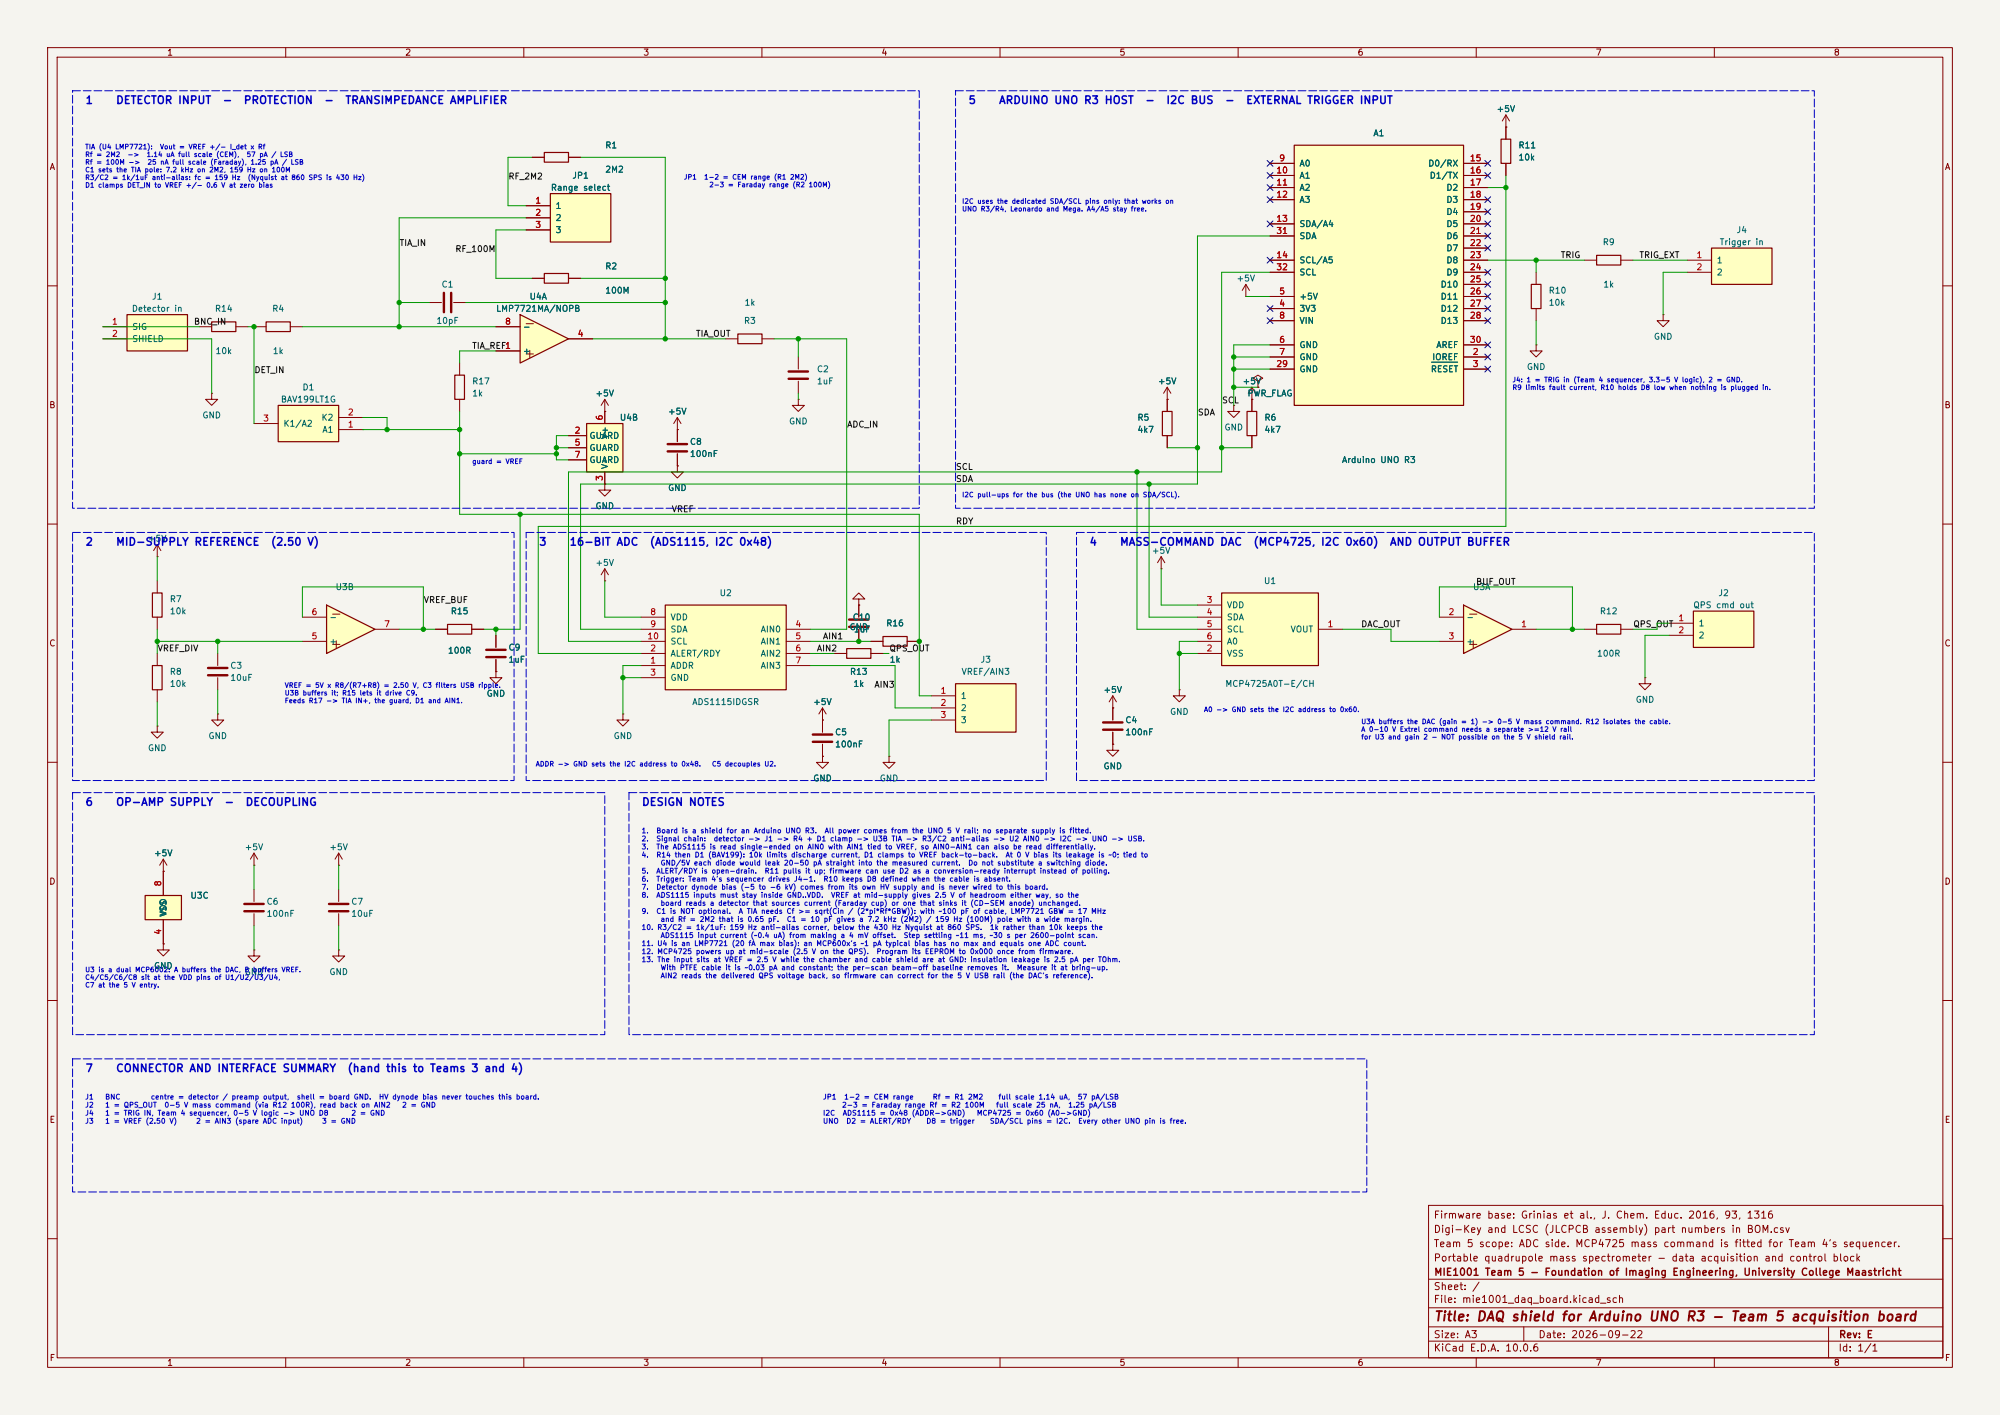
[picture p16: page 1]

TIA (U4 LMP7721): Vout = VREF +/- I_det x Rf Rf = 2M2 -> 1.14 uA full scale (CEM), 57 pA / LSB

Rf = 100M -> 25 nA full scale (Faraday), 1.25 pA / LSB
C1 sets the TIA pole: 7.2 kHz on 2M2, 159 Hz on 100M
R3/C2 = 1k/1uF anti-alias: fc = 159 Hz (Nyquist at 860 SPS is 430 Hz) D1 clamps DET_IN to VREF +/- 0.6 V at zero bias

I2C uses the dedicated SDA/SCL pins only: that works on UNO R3/R4, Leonardo and Mega. A4/A5 stay free. DESIGN NOTES

J2 QPS cmd out GND
J4: 1 = TRIG in (Team 4 sequencer, 3.3-5 V logic), 2 = GND. R9 limits fault current, R10 holds D8 low when nothing is plugged in.

I2C pull-ups for the bus (the UNO has none on SDA/SCL).

U3A buffers the DAC (gain = 1) -> 0-5 V mass command. R12 isolates the cable. A 0-10 V Extrel command needs a separate >=12 V rail for U3 and gain 2 - NOT possible on the 5 V shield rail. 1. Board is a shield for an Arduino UNO R3. All power comes from the UNO 5 V rail; no separate supply is fitted. 2. Signal chain: detector -> J1 -> R4 + D1 clamp -> U3B TIA -> R3/C2 anti-alias -> U2 AIN0 -> I2C -> UNO -> USB. 3. The ADS1115 is read single-ended on AIN0 with AIN1 tied to VREF, so AIN0-AIN1 can also be read differentially. 4. R14 then D1 (BAV199): 10k limits discharge current, D1 clamps to VREF back-to-back. At 0 V bias its leakage is ~0; tied to GND/5V each diode would leak 20-50 pA straight into the measured current. Do not substitute a switching diode. 5. ALERT/RDY is open-drain. R11 pulls it up; firmware can use D2 as a conversion-ready interrupt instead of polling. 6. Trigger: Team 4's sequencer drives J4-1. R10 keeps D8 defined when the cable is absent. 7. Detector dynode bias (-5 to -6 kV) comes from its own HV supply and is never wired to this board. 8. ADS1115 inputs must stay inside GND..VDD. VREF at mid-supply gives 2.5 V of headroom either way, so the board reads a detector that sources current (Faraday cup) or one that sinks it (CD-SEM anode) unchanged. 9. C1 is NOT optional. A TIA needs Cf >= sqrt(Cin / (2*pi*Rf*GBW)): with ~100 pF of cable, LMP7721 GBW = 17 MHz and Rf = 2M2 that is 0.65 pF. C1 = 10 pF gives a 7.2 kHz (2M2) / 159 Hz (100M) pole with a wide margin. 10. R3/C2 = 1k/1uF: 159 Hz anti-alias corner, below the 430 Hz Nyquist at 860 SPS. 1k rather than 10k keeps the

U3 is a dual MCP6002: A buffers the DAC, B buffers VREF. C4/C5/C6/C8 sit at the VDD pins of U1/U2/U3/U4, C7 at the 5 V entry.

Firmware base: Grinias et al., J. Chem. Educ. 2016, 93, 1316
Digi-Key and LCSC (JLCPCB assembly) part numbers in BOM.csv
Team 5 scope: ADC side. MCP4725 mass command is fitted for Team 4's sequencer.
Portable quadrupole mass spectrometer - data acquisition and control block
MIE1001 Team 5 - Foundation of Imaging Engineering, University College Maastricht
Sheet: /
File: mie1001_daq_board.kicad_sch
Title: DAQ shield for Arduino UNO R3 - Team 5 acquisition board

Size: A3 | Rev: E | F Date: 2026-09-22
KiCad E.D.A. 10.0.6 | Id: 1/1

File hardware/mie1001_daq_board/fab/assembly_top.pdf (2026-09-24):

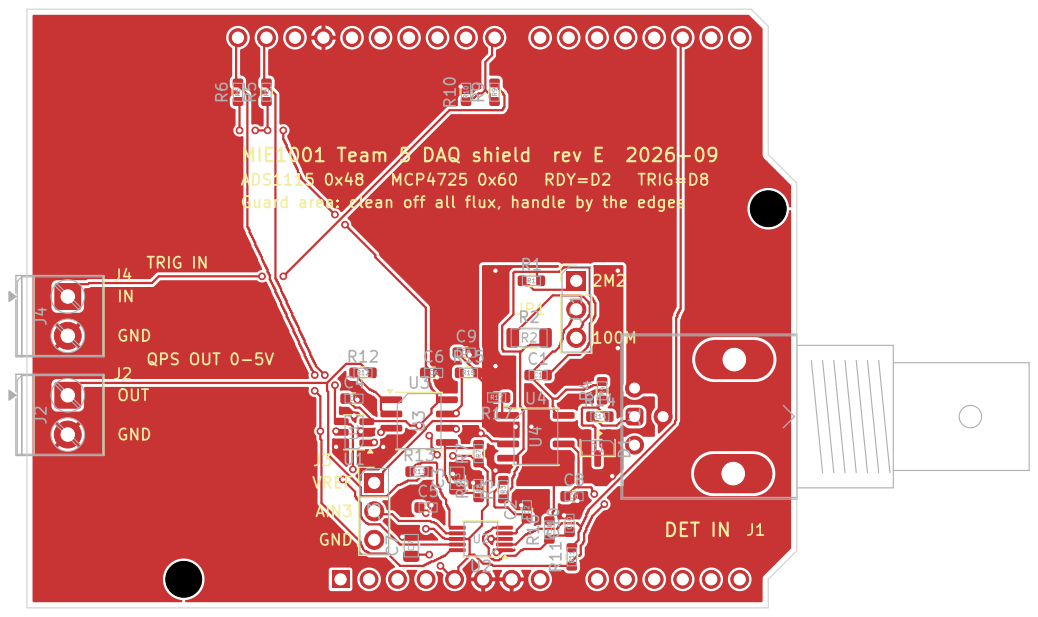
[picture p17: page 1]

AIN3 GND MIE1001 Team 5 DAQ shield rev E 2026-09 DET IN

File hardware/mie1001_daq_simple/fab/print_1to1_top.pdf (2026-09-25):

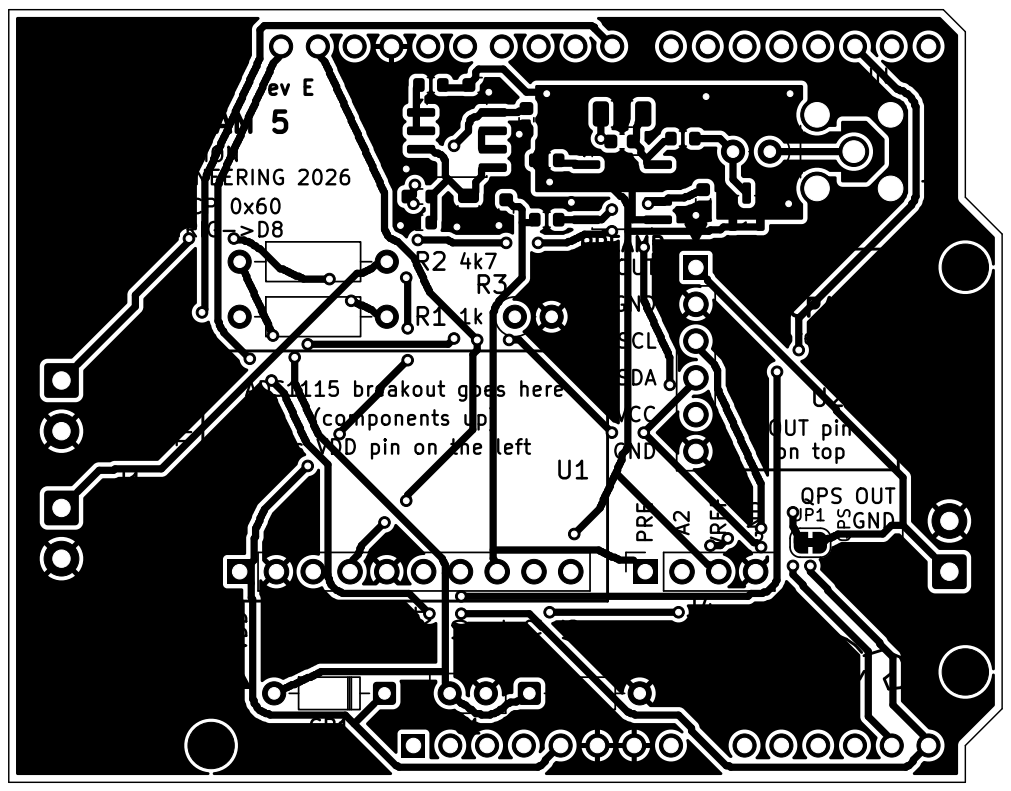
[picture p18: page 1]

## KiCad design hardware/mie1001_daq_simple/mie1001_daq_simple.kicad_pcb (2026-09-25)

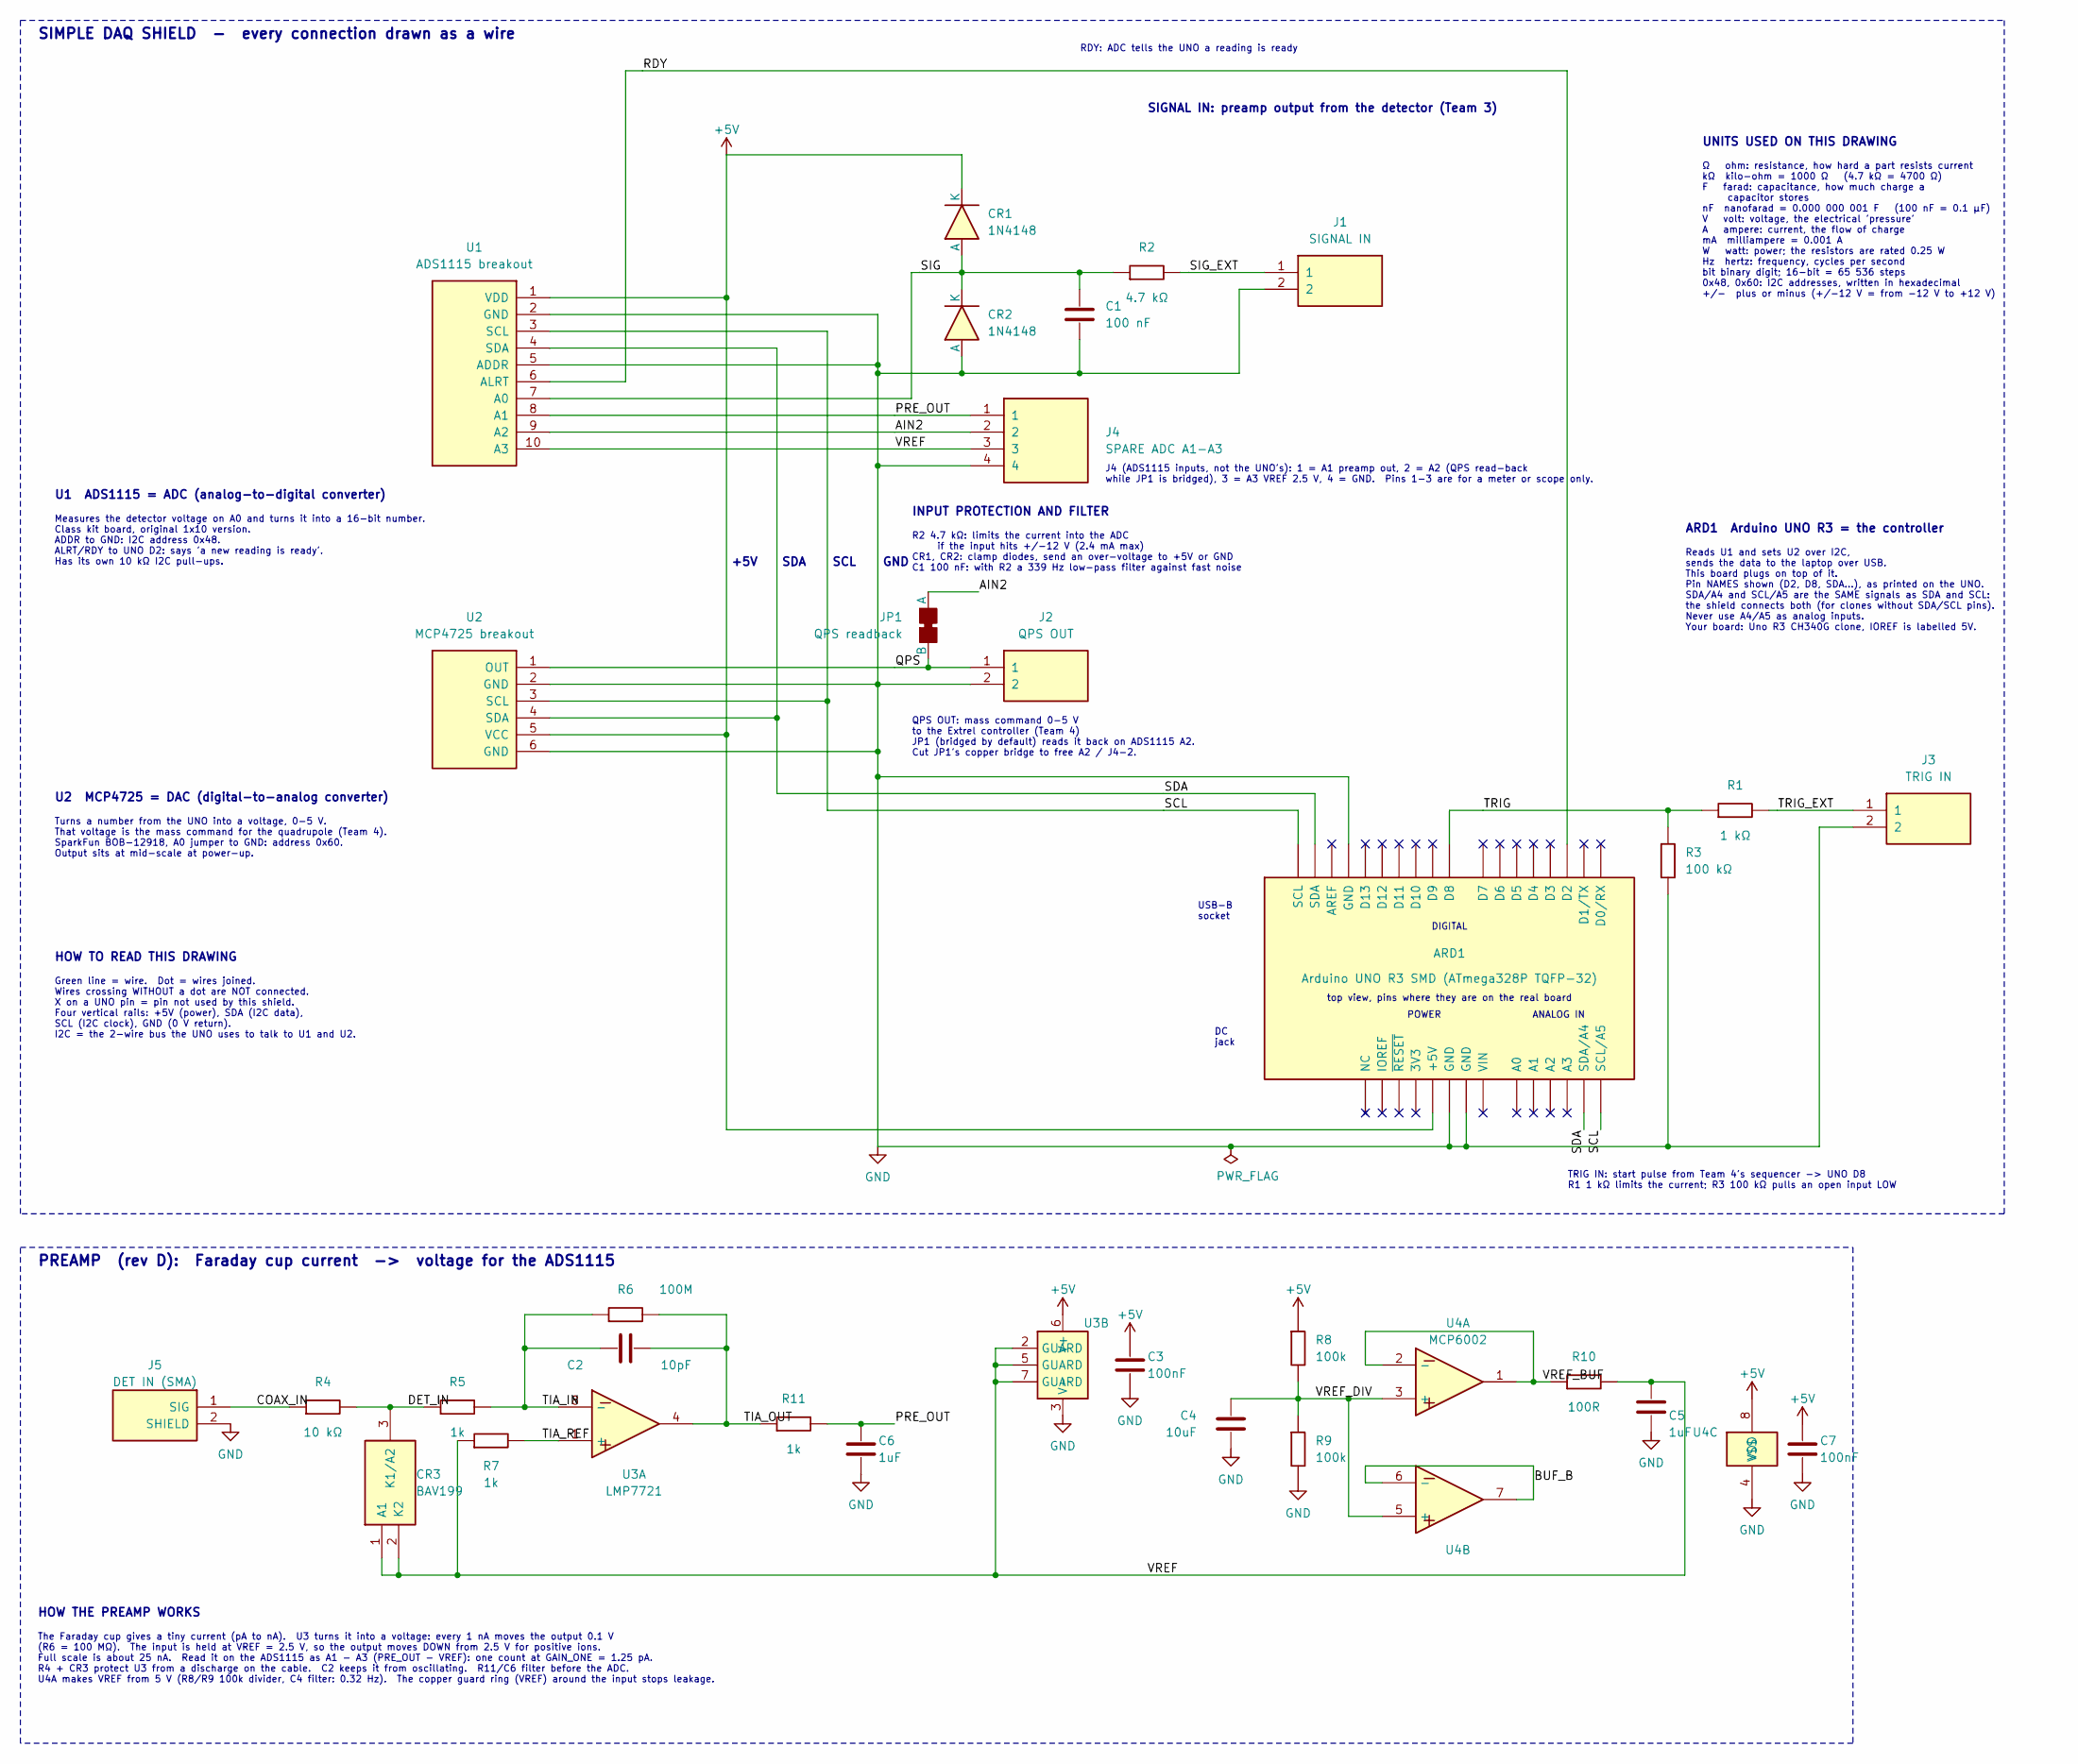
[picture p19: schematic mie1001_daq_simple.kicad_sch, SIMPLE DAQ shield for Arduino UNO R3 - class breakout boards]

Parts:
ARD1: Arduino UNO R3 SMD (ATmega328P TQFP-32); Arduino_UNO_R3; Rating Arduino UNO R3 SMD (ATmega328P TQFP-32); MPN UNO R3 SMD CH340 clone (marked V1888); 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; Digi-Key P/N do not order: use your own board
C1: 100 nF; C_Disc_D5.0mm_W2.5mm_P2.50mm; Rating 100 nF 50 V X7R ceramic; MPN K104K15X7RF5TL2; Digi-Key P/N BC1084CT-ND
C2: 10pF; C_0603_1608Metric; Rating 10pF C0G 50V 0603; MPN CL10C100JB8NNNC; Digi-Key P/N 1276-1027-1-ND
C3, C7: 100nF; C_0603_1608Metric; Rating 100nF X7R 50V 0603; MPN 885012206095; Digi-Key P/N 732-8013-1-ND
C4: 10uF; C_0805_2012Metric; Rating 10uF X5R 25V 0805; MPN TMK212BBJ106KGHT; Digi-Key P/N 587-4334-1-ND
C5, C6: 1uF; C_0603_1608Metric; Rating 1uF X5R 25V 0603; MPN CL10A105KA8NNNC; Digi-Key P/N 1276-1102-1-ND
CR1, CR2: 1N4148; D_DO-35_SOD27_P7.62mm_Horizontal; Rating 1N4148; MPN 1N4148; Digi-Key P/N 1N4148FS-ND
CR3: BAV199; SOT-23; Rating BAV199LT1G; MPN BAV199LT1G; Digi-Key P/N BAV199LT1GOSCT-ND
J1: SIGNAL IN; TerminalBlock_Phoenix_PT-1,5-2-3.5-H_1x02_P3.50mm_Horizontal; Rating Signal in; MPN 1984617; Digi-Key P/N 277-1721-ND
J2: QPS OUT; TerminalBlock_Phoenix_PT-1,5-2-3.5-H_1x02_P3.50mm_Horizontal; Rating QPS out; MPN 1984617; Digi-Key P/N 277-1721-ND
J3: TRIG IN; TerminalBlock_Phoenix_PT-1,5-2-3.5-H_1x02_P3.50mm_Horizontal; Rating Trigger in; MPN 1984617; Digi-Key P/N 277-1721-ND
J4: SPARE ADC A1-A3; PinSocket_1x04_P2.54mm_Vertical; Rating Spare ADC in; MPN PPTC041LFBN-RC; Digi-Key P/N S7002-ND
J5: DET IN (SMA); SMA_Amphenol_132134_Vertical; Rating Detector in, SMA jack vertical; MPN 132134; Digi-Key P/N ACX1230-ND
JP1: QPS readback; SolderJumper-2_P1.3mm_Bridged_RoundedPad1.0x1.5mm
R1: 1 kΩ; R_Axial_DIN0207_L6.3mm_D2.5mm_P10.16mm_Horizontal; Rating 1 kOhm 0.25 W; MPN CFR-25JB-52-1K; Digi-Key P/N 1.0KQBK-ND
R2: 4.7 kΩ; R_Axial_DIN0207_L6.3mm_D2.5mm_P10.16mm_Horizontal; Rating 4.7 kOhm 0.25 W; MPN CFR-25JB-52-4K7; Digi-Key P/N 13-CFR-25JB-52-4K7-ND
R3: 100 kΩ; R_Axial_DIN0207_L6.3mm_D2.5mm_P2.54mm_Vertical; Rating 100 kOhm 0.25 W; MPN CFR-25JB-52-100K; Digi-Key P/N 13-CFR-25JB-52-100K-ND
R4: 10 kΩ; R_Axial_DIN0207_L6.3mm_D2.5mm_P2.54mm_Vertical; Rating 10 kOhm 0.25 W; MPN CFR-25JB-52-10K; Digi-Key P/N 13-CFR-25JB-52-10K-ND
R5, R7, R11: 1k; R_0603_1608Metric; Rating 1k 1% 0603; MPN RC0603FR-071KL; Digi-Key P/N 311-1.00KHRCT-ND
R6: 100M; R_1206_3216Metric; Rating 100M 1% 1206; MPN HVCB1206FKC100M; Digi-Key P/N HVCB1206FKC100MCT-ND
R8, R9: 100k; R_0603_1608Metric; Rating 100k 1% 0603; MPN RC0603FR-07100KL; Digi-Key P/N 311-100KHRCT-ND
R10: 100R; R_0603_1608Metric; Rating 100R 1% 0603; MPN RC0603FR-07100RL; Digi-Key P/N 311-100HRCT-ND
U1: ADS1115 breakout; PinSocket_1x10_P2.54mm_Vertical; Rating Adafruit ADS1115 breakout (original, 1x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; MPN 1085 (ORIGINAL 1x10 version, from the c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; Digi-Key P/N do not order
U2: MCP4725 breakout; PinSocket_1x06_P2.54mm_Vertical; Rating SparkFun MCP4725 breakout; MPN 12918; Digi-Key P/N 1568-12918-ND
U3: LMP7721; SOIC-8_3.9x4.9mm_P1.27mm; Rating LMP7721MA/NOPB; MPN LMP7721MA/NOPB; Digi-Key P/N LMP7721MA/NOPB-ND
U4: MCP6002; SOIC-8_3.9x4.9mm_P1.27mm; Rating MCP6002-I/SN; MPN MCP6002-I/SN; Digi-Key P/N MCP6002-I/SN-ND

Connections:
+5V: ARD1.5 (+5V), C3.1, C7.1, CR1.1 (K), R8.1, U1.1 (VDD), U2.5 (VCC), U3.6 (V+), U4.8 (VDD)
/AIN2: J4.2, JP1.1 (A), U1.9 (A2)
/BUF_B: U4.6 (-), U4.7
/COAX_IN: J5.1 (SIG), R4.1
/DET_IN: CR3.3 (K1/A2), R4.2, R5.1
/PRE_OUT: C6.1, J4.1, R11.2, U1.8 (A1)
/QPS: J2.1, JP1.2 (B), U2.1 (OUT)
/RDY: ARD1.17 (D2), U1.6 (ALRT)
/SCL: ARD1.14 (SCL/A5), ARD1.32 (SCL), U1.3 (SCL), U2.3 (SCL)
/SDA: ARD1.13 (SDA/A4), ARD1.31 (SDA), U1.4 (SDA), U2.4 (SDA)
/SIG: C1.1, CR1.2 (A), CR2.1 (K), R2.1, U1.7 (A0)
/SIG_EXT: J1.1, R2.2
/TIA_IN: C2.1, R5.2, R6.1, U3.8 (-)
/TIA_OUT: C2.2, R6.2, R11.1, U3.4
/TIA_REF: R7.2, U3.1 (+)
/TRIG: ARD1.23 (D8), R1.1, R3.1
/TRIG_EXT: J3.1, R1.2
/VREF: C5.1, CR3.1 (A1), CR3.2 (K2), J4.3, R7.1, R10.2, U1.10 (A3), U3.2 (GUARD), U3.5 (GUARD), U3.7 (GUARD)
/VREF_BUF: R10.1, U4.1, U4.2 (-)
/VREF_DIV: C4.1, R8.2, R9.1, U4.3 (+), U4.5 (+)
GND: ARD1.6 (GND), ARD1.7 (GND), ARD1.29 (GND), C1.2, C3.2, C4.2, C5.2, C6.2, C7.2, CR2.2 (A), J1.2, J2.2, J3.2, J4.4, J5.2 (SHIELD), R3.2, R9.2, U1.2 (GND), U1.5 (ADDR), U2.2 (GND), U2.6 (GND), U3.3 (V-), U4.4 (VSS)

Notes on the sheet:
SIMPLE DAQ SHIELD - every connection drawn as a wire
USB-B socket
DC jack
top view, pins where they are on the real board
POWER
ANALOG IN
DIGITAL
U1 ADS1115 = ADC (analog-to-digital converter)
Measures the detector voltage on A0 and turns it into a 16-bit number. Class kit board, original 1x10 version. ADDR to GND: I2C address 0x48. ALRT/RDY to UNO D2: says 'a new reading is ready'. Has its own 10 kΩ I2C pull-ups.
U2 MCP4725 = DAC (digital-to-analog converter)
Turns a number from the UNO into a voltage, 0-5 V. That voltage is the mass command for the quadrupole (Team 4). SparkFun BOB-12918, A0 jumper to GND: address 0x60. Output sits at mid-scale at power-up.
HOW TO READ THIS DRAWING
Green line = wire. Dot = wires joined. Wires crossing WITHOUT a dot are NOT connected. X on a UNO pin = pin not used by this shield. Four vertical rails: +5V (power), SDA (I2C data), SCL (I2C clock), GND (0 V return). I2C = the 2-wire bus the UNO uses to talk to U1 and U2.
+5V
SDA
SCL
GND
ARD1 Arduino UNO R3 = the controller
Reads U1 and sets U2 over I2C, sends the data to the laptop over USB. This board plugs on top of it. Pin NAMES shown (D2, D8, SDA...), as printed on the UNO. SDA/A4 and SCL/A5 are the SAME signals as SDA and SCL: the shield connects both (for clones without SDA/SCL pins). Never use A4/A5 as analog 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
SIGNAL IN: preamp output from the detector (Team 3)
RDY: ADC tells the UNO a reading is ready
UNITS USED ON THIS DRAWING
Ω ohm: resistance, how hard a part resists current kΩ kilo-ohm = 1000 Ω (4.7 kΩ = 4700 Ω) F farad: capacitance, how much charge a capacitor stores nF nanofarad = 0.000 000 001 F (100 nF = 0.1 µF) V volt: voltage, the electrical 'pressure' A ampere: current, the flow of charge mA milliampere = 0.001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
INPUT PROTECTION AND FILTER
R2 4.7 kΩ: limits the current into the ADC if the input hits +/-12 V (2.4 mA max) CR1, CR2: clamp diodes, send an over-voltage to +5V or GND C1 100 nF: with R2 a 339 Hz low-pass filter against fast noise
J4 (ADS1115 inputs, not the UNO's): 1 = A1 preamp out, 2 = A2 (QPS read-back while JP1 is bridged), 3 = A3 VREF 2.5 V, 4 = GND. Pins 1-3 are for a meter or scope only.
QPS OUT: mass command 0-5 V to the Extrel controller (Team 4) JP1 (bridged by default) reads it back on ADS1115 A2. Cut JP1's copper bridge to free A2 / J4-2.
TRIG IN: start pulse from Team 4's sequencer -> UNO D8 R1 1 kΩ limits the current; R3 100 kΩ pulls an open input LOW
PREAMP (rev D): Faraday cup current -> voltage for the ADS1115
HOW THE PREAMP WORKS
The Faraday cup gives a tiny current (pA to nA). U3 turns it into a voltage: every 1 nA moves the output 0.1 V (R6 = 100 MΩ). The input is held at VREF = 2.5 V, so the output moves DOWN from 2.5 V for positive ions. Full scale is about 25 nA. Read it on the ADS1115 as A1 - A3 (PRE_OUT - VREF): one 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

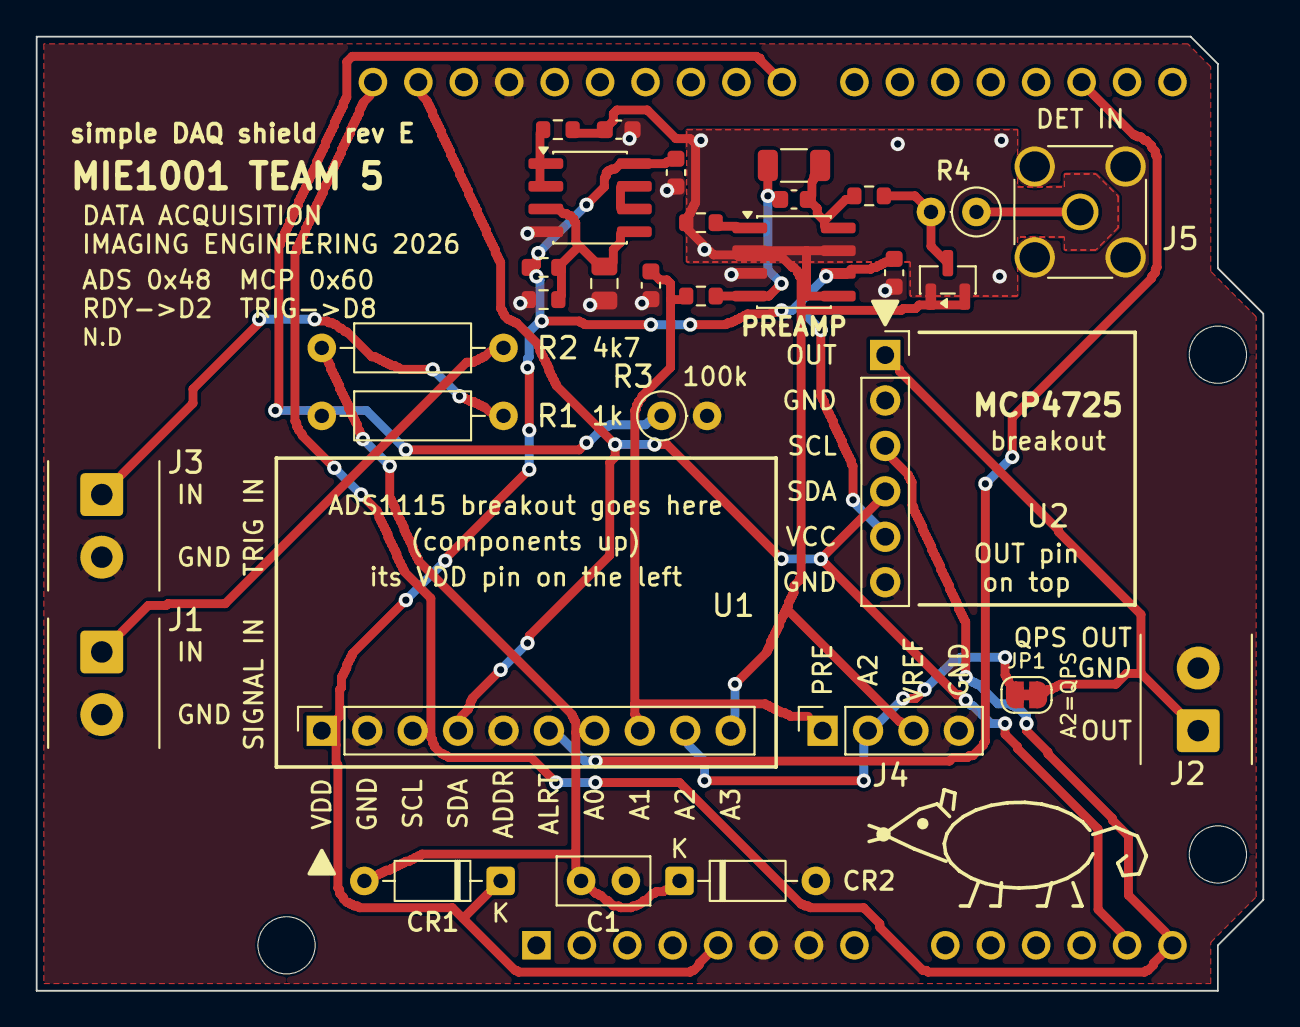
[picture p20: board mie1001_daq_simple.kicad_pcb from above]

Board: 2 copper layers, 68.6 x 53.3 mm, 35 parts (1 on the bottom side), 21 nets.

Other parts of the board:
H1, H2, H3: MountingHole_3.2mm_M3

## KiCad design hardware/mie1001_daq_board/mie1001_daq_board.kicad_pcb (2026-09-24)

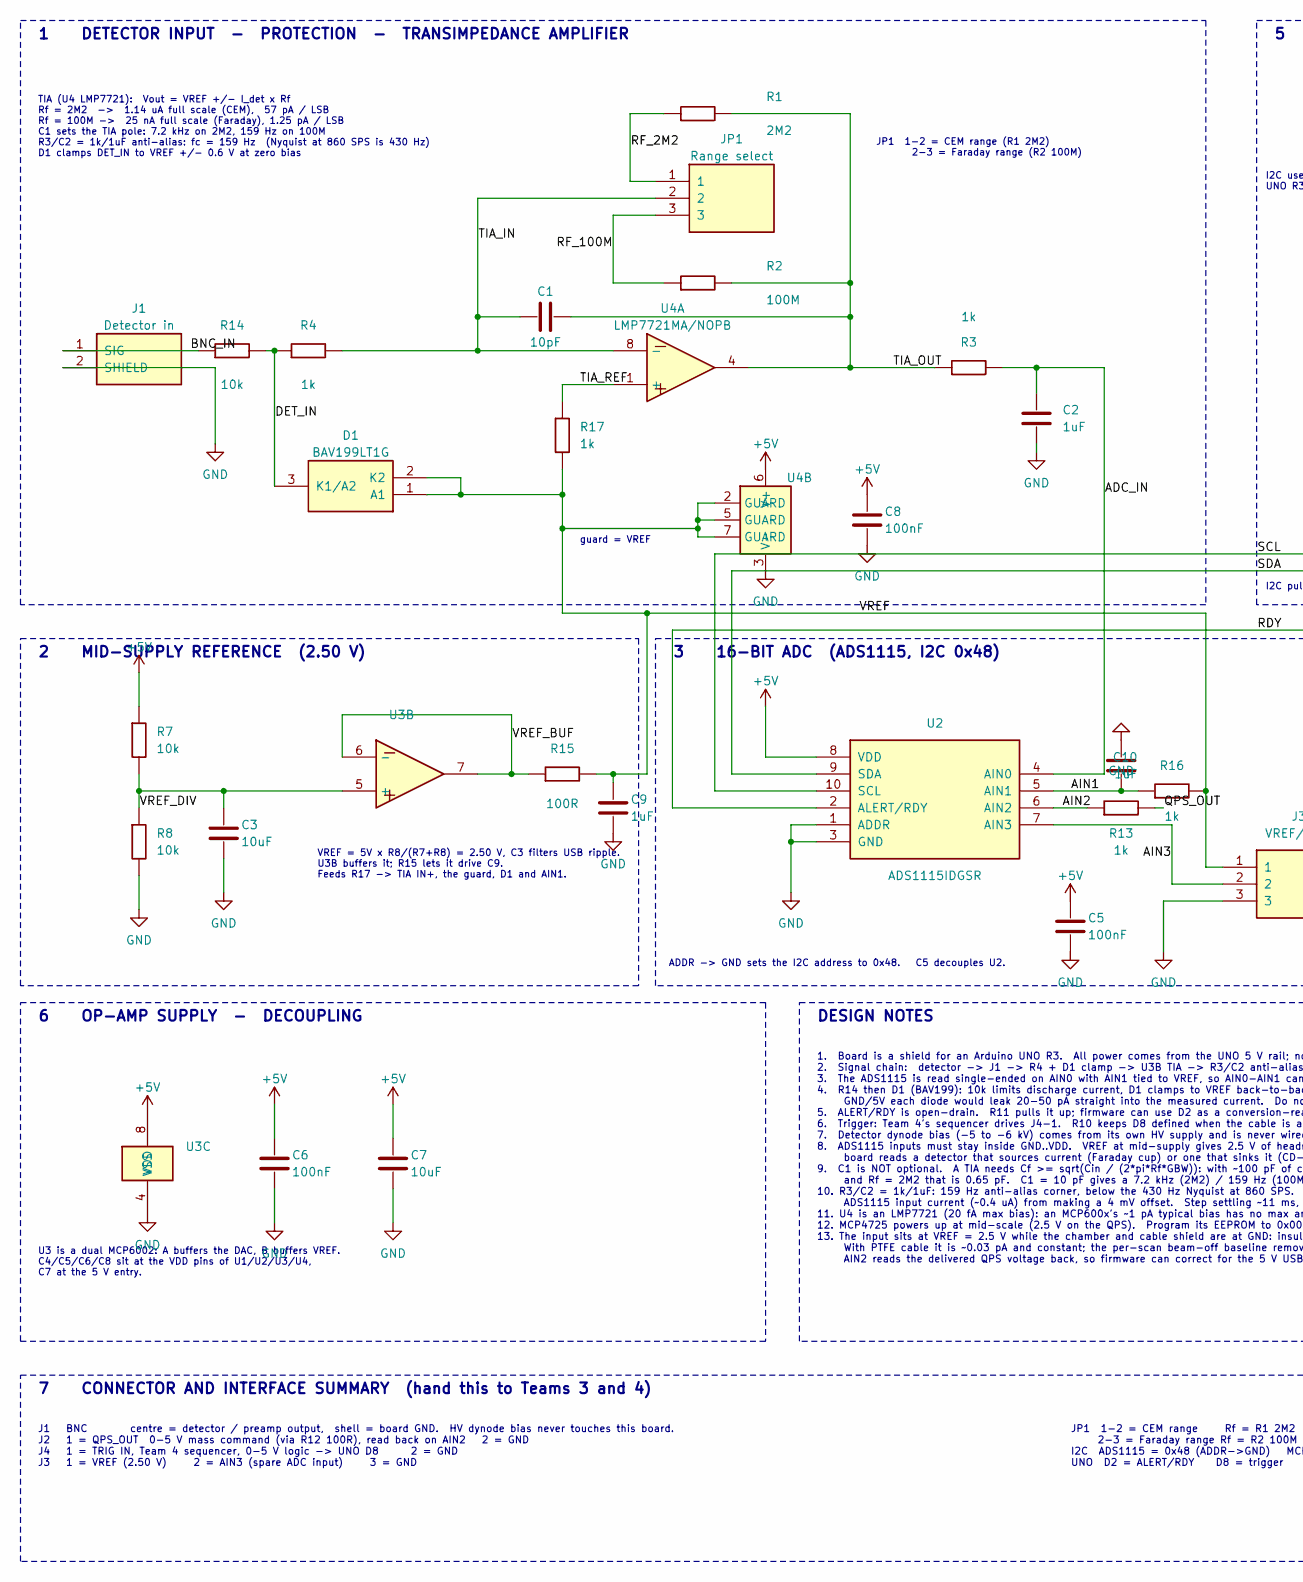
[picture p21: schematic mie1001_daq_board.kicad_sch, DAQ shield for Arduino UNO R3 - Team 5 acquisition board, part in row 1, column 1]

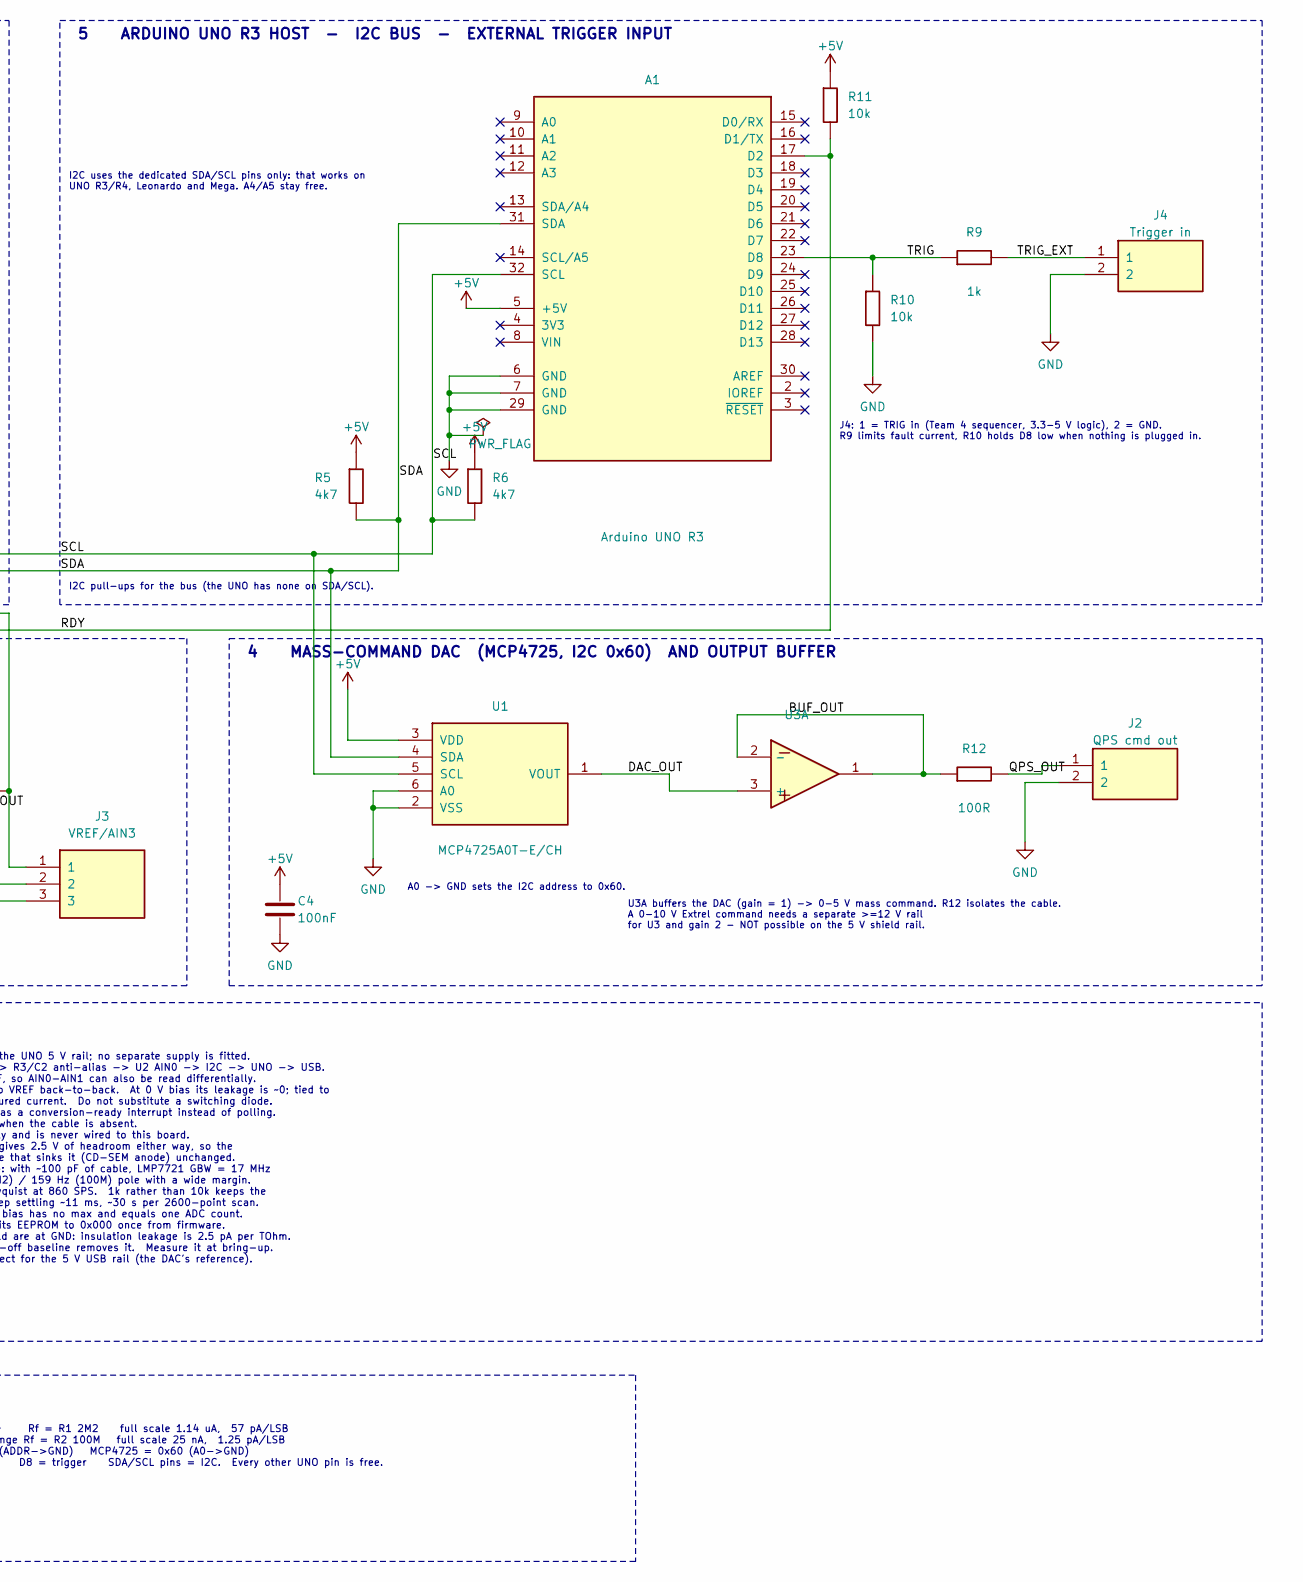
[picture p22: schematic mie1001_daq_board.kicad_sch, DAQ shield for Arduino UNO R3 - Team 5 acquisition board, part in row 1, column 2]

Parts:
A1: Arduino UNO R3; Arduino_UNO_R3; Rating Arduino UNO R3; MPN A000066; Digi-Key P/N 1050-1024-ND
C1: 10pF; C_0603_1608Metric; Rating 10pF C0G 50V 0603; MPN GRM1885C1H100JA01D; Digi-Key P/N 490-1403-1-ND
C2, C9, C10: 1uF; C_0603_1608Metric; Rating 1uF X5R 50V 0603; MPN CL10A105KB8NNNC; Digi-Key P/N 1276-1860-1-ND
C3, C7: 10uF; C_0805_2012Metric; Rating 10uF X5R 25V 0805; MPN CL21A106KAYNNNE; Digi-Key P/N 1276-2891-1-ND
C4, C5, C6, C8: 100nF; C_0603_1608Metric; Rating 100nF X7R 50V 0603; MPN CL10B104KB8NNNC; Digi-Key P/N 1276-1000-1-ND
D1: BAV199LT1G; SOT-23; Rating BAV199LT1G; MPN BAV199LT1G; Digi-Key P/N BAV199LT1GOSCT-ND
J1: Detector in; BNC_Amphenol_031-6575_Horizontal; Rating Detector in, BNC; MPN 031-6575; Digi-Key P/N ARF2111-ND
J2: QPS cmd out; TerminalBlock_Phoenix_PT-1,5-2-3.5-H_1x02_P3.50mm_Horizontal; Rating QPS mass cmd out; MPN 1984617; Digi-Key P/N 277-1721-ND
J3: VREF/AIN3; PinHeader_1x03_P2.54mm_Vertical; Rating VREF / AIN3 / GND; MPN PRPC040SAAN-RC; Digi-Key P/N S1011EC-40-ND
J4: Trigger in; TerminalBlock_Phoenix_PT-1,5-2-3.5-H_1x02_P3.50mm_Horizontal; Rating Trigger in; MPN 1984617; Digi-Key P/N 277-1721-ND
JP1: Range select; PinHeader_1x03_P2.54mm_Vertical; Rating TIA range select; MPN PRPC040SAAN-RC; Digi-Key P/N S1011EC-40-ND
R1: 2M2; R_0603_1608Metric; Rating 2M2 1% 0603; MPN RC0603FR-072M2L; Digi-Key P/N YAG3329CT-ND
R2: 100M; R_1206_3216Metric; Rating 100M 1% 1206; MPN HVCB1206FKC100M; Digi-Key P/N HVCB1206FKC100MCT-ND
R3, R4, R9, R13, R16, R17: 1k; R_0603_1608Metric; Rating 1k 1% 0603; MPN RC0603FR-071KL; Digi-Key P/N 311-1.00KHRCT-ND
R5, R6: 4k7; R_0603_1608Metric; Rating 4k7 1% 0603; MPN RC0603FR-074K7L; Digi-Key P/N 311-4.70KHRCT-ND
R7, R8, R10, R11: 10k; R_0603_1608Metric; Rating 10k 1% 0603; MPN RC0603FR-0710KL; Digi-Key P/N 311-10.0KHRCT-ND
R12, R15: 100R; R_0603_1608Metric; Rating 100R 1% 0603; MPN RC0603FR-07100RL; Digi-Key P/N 311-100HRCT-ND
R14: 10k; R_0603_1608Metric; Rating 10k 1% 0603 anti-surge; MPN ERJ-PA3F1002V; Digi-Key P/N P10KBYCT-ND
U1: MCP4725A0T-E/CH; SOT-23-6; Rating MCP4725A0T-E/CH; MPN MCP4725A0T-E/CH; Digi-Key P/N MCP4725A0T-E/CHCT-ND
U2: ADS1115IDGSR; MSOP-10_3x3mm_P0.5mm; Rating ADS1115IDGSR; MPN ADS1115IDGSR; Digi-Key P/N 296-38849-1-ND
U3: MCP6002-I/SN; SOIC-8_3.9x4.9mm_P1.27mm; Rating MCP6002-I/SN; MPN MCP6002-I/SN; Digi-Key P/N MCP6002-I/SN-ND
U4: LMP7721MA/NOPB; SOIC-8_3.9x4.9mm_P1.27mm; Rating LMP7721MA/NOPB; MPN LMP7721MA/NOPB; Digi-Key P/N LMP7721MA/NOPB-ND

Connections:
+5V: A1.5 (+5V), C4.1, C5.1, C6.1, C7.1, C8.1, R5.1, R6.1, R7.1, R11.1, U1.3 (VDD), U2.8 (VDD), U3.8 (VDD), U4.6 (V+)
/ADC_IN: C2.1, R3.2, U2.4 (AIN0)
/AIN1: C10.1, R16.1, U2.5 (AIN1)
/AIN2: R13.1, U2.6 (AIN2)
/AIN3: J3.2, U2.7 (AIN3)
/BNC_IN: J1.1 (SIG), R14.1
/BUF_OUT: R12.1, U3.1, U3.2 (-)
/DAC_OUT: U1.1 (VOUT), U3.3 (+)
/DET_IN: D1.3 (K1/A2), R4.1, R14.2
/QPS_OUT: J2.1, R12.2, R13.2
/RDY: A1.17 (D2), R11.2, U2.2 (ALERT/RDY)
/RF_2M2: JP1.1, R1.1
/RF_100M: JP1.3, R2.1
/SCL: A1.32 (SCL), R6.2, U1.5 (SCL), U2.10 (SCL)
/TIA_IN: C1.1, JP1.2, R4.2, U4.8 (-)
/TIA_OUT: C1.2, R1.2, R2.2, R3.1, U4.4
/TIA_REF: R17.1, U4.1 (+)
/TRIG: A1.23 (D8), R9.1, R10.1
/TRIG_EXT: J4.1, R9.2
/VREF: C9.1, D1.1 (A1), D1.2 (K2), J3.1, R15.2, R16.2, R17.2, U4.2 (GUARD), U4.5 (GUARD), U4.7 (GUARD)
/VREF_BUF: R15.1, U3.6 (-), U3.7
/VREF_DIV: C3.1, R7.2, R8.1, U3.5 (+)

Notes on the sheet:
1 DETECTOR INPUT - PROTECTION - TRANSIMPEDANCE AMPLIFIER
guard = VREF
JP1 1-2 = CEM range (R1 2M2) 2-3 = Faraday range (R2 100M)
TIA (U4 LMP7721): Vout = VREF +/- I_det x Rf Rf = 2M2 -> 1.14 uA full scale (CEM), 57 pA / LSB Rf = 100M -> 25 nA full scale (Faraday), 1.25 pA / LSB C1 sets the TIA pole: 7.2 kHz on 2M2, 159 Hz on 100M R3/C2 = 1k/1uF anti-alias: fc = 159 Hz (Nyquist at 860 SPS is 430 Hz) D1 clamps DET_IN to VREF +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
5 ARDUINO UNO R3 HOST - I2C BUS - EXTERNAL TRIGGER INPUT
I2C uses the dedicated SDA/SCL pins only: that works on UNO R3/R4, Leonardo and Mega. A4/A5 stay free.
I2C pull-ups for the bus (the UNO has none on SDA/SCL).
J4: 1 = TRIG in (Team 4 sequencer, 3.3-5 V logic), 2 = GND. R9 limits fault current, R10 holds D8 low when nothing is plugged in.
2 MID-SUPPLY REFERENCE (2.50 V)
VREF = 5V x R8/(R7+R8) = 2.50 V, C3 filters USB ripple. U3B buffers it; R15 lets it drive C9. Feeds R17 -> TIA IN+, the guard, D1 and AIN1.
3 16-BIT ADC (ADS1115, I2C 0x48)
ADDR -> GND sets the I2C address to 0x48. C5 decouples U2.
4 MASS-COMMAND DAC (MCP4725, I2C 0x60) AND OUTPUT BUFFER
A0 -> GND sets the I2C address to 0x60.
U3A buffers the DAC (gain = 1) -> 0-5 V mass command. R12 isolates the cable. A 0-10 V Extrel command needs a separate >=12 V rail for U3 and gain 2 - NOT possible on the 5 V shield rail.
6 OP-AMP SUPPLY - DECOUPLING
U3 is a dual MCP6002: A buffers the DAC, B buffers VREF. C4/C5/C6/C8 sit at the VDD pins of U1/U2/U3/U4, C7 at the 5 V entry.
DESIGN NOTES
1. Board is a shield for an Arduino UNO R3. All power comes from the UNO 5 V rail; no separate supply is fitted. 2. Signal chain: detector -> J1 -> R4 + D1 clamp -> U3B TIA -> R3/C2 anti-alias -> U2 AIN0 -> I2C -> UNO -> USB. 3. The ADS1115 is read single-ended on AIN0 with AIN1 tied to VREF, so AI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
7 CONNECTOR AND INTERFACE SUMMARY (hand this to Teams 3 and 4)
J1 BNC centre = detector / preamp output, shell = board GND. HV dynode bias never touches this board. J2 1 = QPS_OUT 0-5 V mass command (via R12 100R), read back on AIN2 2 = GND J4 1 = TRIG IN, Team 4 sequencer, 0-5 V logic -> UNO D8 2 = GND J3 1 = VREF (2.50 V) 2 = AIN3 (spare ADC input) 3 = GND
JP1 1-2 = CEM range Rf = R1 2M2 full scale 1.14 uA, 57 pA/LSB 2-3 = Faraday range Rf = R2 100M full scale 25 nA, 1.25 pA/LSB I2C ADS1115 = 0x48 (ADDR->GND) MCP4725 = 0x60 (A0->GND) UNO D2 = ALERT/RDY D8 = trigger SDA/SCL pins = I2C. Every other UNO pin is free.

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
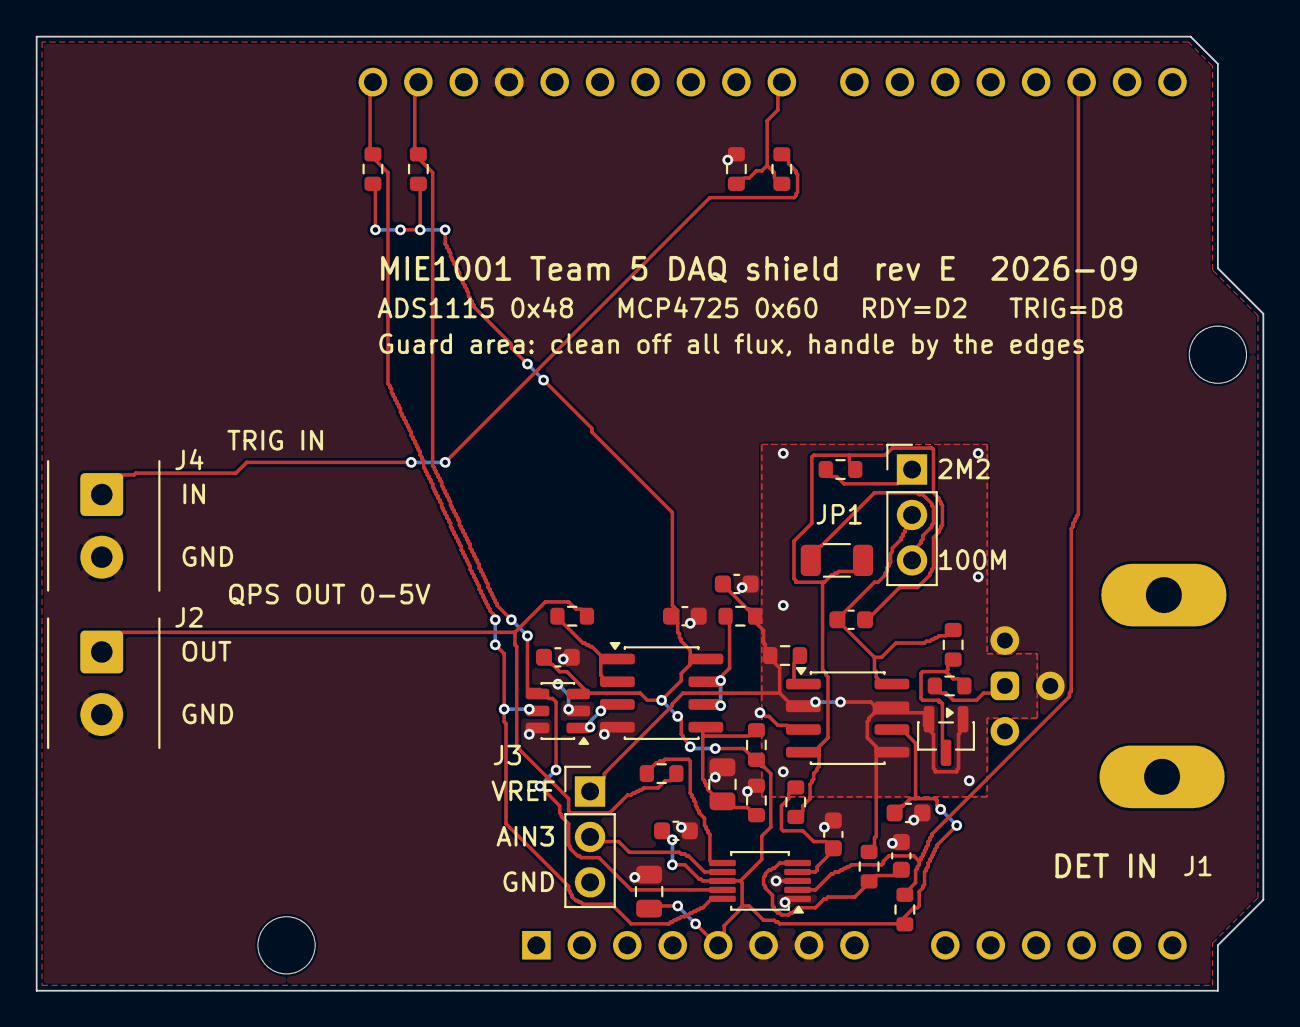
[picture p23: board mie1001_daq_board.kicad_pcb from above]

Board: 2 copper layers, 68.6 x 53.3 mm, 40 parts (1 on the bottom side), 24 nets.

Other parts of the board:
H1, H2: MountingHole_3.2mm_M3

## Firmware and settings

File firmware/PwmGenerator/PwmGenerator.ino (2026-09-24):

/*
 * PwmGenerator - a pulse width modulator for Uno / Nano / Pro Mini.
 *
 * Two independent-duty PWM outputs on a shared, freely chosen frequency:
 *
 *     pin 9  = channel A
 *     pin 10 = channel B
 *
 * Drive it over the serial monitor at 115200 baud, 'Newline' line ending:
 *
 *     f 20000     set frequency to 20 kHz (0.25 Hz .. 1 MHz)
 *     a 37.5      channel A duty, in percent
 *     b 90        channel B duty, in percent
 *     ph 90       shift channel B 90 degrees behind channel A
 *     pot on|off  let A0 control channel A's duty instead
 *     sweep       one 0 -> 100 -> 0 % ramp on channel A
 *     s           status
 *     ?           this list
 *
 * Optional hardware: a potentiometer's wiper on A0, an LED + ~220R resistor
 * (or a scope probe) on pin 9. Nothing extra is required to try the commands.
 */

/*
 * Pwm16 - hardware PWM on Timer1 (ATmega328P: Uno, Nano, Pro Mini)
 *
 *   Channel A -> pin 9   (OC1A / PB1)
 *   Channel B -> pin 10  (OC1B / PB2)
 *
 * Two operating modes, switched automatically by pwmSetPhase():
 *
 *   phase == 0  HARDWARE mode. Fast PWM, TOP in ICR1, both pins driven by the
 *               compare units. Jitter-free, works to 1 MHz. A and B are
 *               edge-aligned: they rise together and differ only in duty.
 *
 *   phase != 0  SOFTWARE mode. Timer1 runs in CTC and an ISR steps through the
 *               edge schedule, driving both pins directly. This buys arbitrary
 *               phase between A and B, and costs ISR latency (a few us) and a
 *               much lower usable frequency ceiling. See pwmMaxLatencyUs().
 *
 * Why the mode switch is necessary rather than just clever: in fast PWM the
 * OCR1A/OCR1B registers are double-buffered and only update at BOTTOM, so one
 * compare unit cannot place two independently-timed edges inside one period.
 * Phase-shifting B against A needs four scheduled edges per period, and Timer1
 * has only two compare units - hence the software scheduler.
 *
 * Timer1 is fully occupied either way, so Servo.h cannot be used alongside.
 * millis(), micros() and delay() live on Timer0 and keep working.
 */

#include <Arduino.h>

enum PwmChannel : uint8_t { PWM_A = 0, PWM_B = 1 };

// ===========================================================================
//  Timer1 driver
// ===========================================================================

#if !defined(__AVR_ATmega328P__) && !defined(__AVR_ATmega168__) && !defined(__AVR_ATmega328__)
#warning "Pwm16 targets the ATmega328P (Uno/Nano/Pro Mini). Timer1 registers may differ on this board."
#endif

static const uint8_t PIN_A = 9;    // OC1A / PB1
static const uint8_t PIN_B = 10;   // OC1B / PB2
static const uint8_t BIT_A = _BV(PB1);
static const uint8_t BIT_B = _BV(PB2);

static const uint16_t kPrescalers[] = {1, 8, 64, 256, 1024};
static const uint8_t  kCsBits[]     = {_BV(CS10),
                                       _BV(CS11),
                                       _BV(CS11) | _BV(CS10),
                                       _BV(CS12),
                                       _BV(CS12) | _BV(CS10)};
static const uint8_t  kNumPrescalers = sizeof(kPrescalers) / sizeof(kPrescalers[0]);

// Cost of the scheduler ISR plus interrupt entry, in CPU cycles. Two edges
// closer together than this cannot both be serviced, so the schedule builder
// spreads them apart and raises the "strained" flag.
//
// Counted from the disassembly of __vector_11: ~127 cycles of body (the C ISR
// saves a lot of registers for the 16-bit array indexing) plus ~5 cycles of
// entry latency. 160 leaves headroom; pwmMaxLatencyUs() reports what the chip
// actually measures, so this constant only has to be a safe upper bound.
static const uint16_t kIsrCycles = 160;

static uint16_t sTop        = 0;     // period - 1, in timer counts
static uint16_t sPrescaler  = 1;
static uint8_t  sCsBits     = _BV(CS10);
static float    sActualHz   = 0.0f;
static float    sDuty[2]    = {0.0f, 0.0f};
static float    sPhaseDeg   = 0.0f;
static bool     sRunning    = false;

// --- software scheduler state ---------------------------------------------
static volatile bool     sSoftMode   = false;
static volatile uint8_t  sEvtCount   = 0;
static volatile uint8_t  sEvtIdx     = 0;
static volatile uint16_t sEvtDelta[4];   // counts from previous event to this one
static volatile uint8_t  sEvtSet[4];     // PORTB bits to raise
static volatile uint8_t  sEvtClr[4];     // PORTB bits to drop
static volatile uint16_t sMaxLatency = 0;
static bool              sStrained   = false;

// In CTC the counter is zeroed by the compare match, so TCNT1 read at ISR entry
// is exactly the latency in timer counts. Free, honest instrumentation.
ISR(TIMER1_COMPA_vect) {
  uint16_t lat = TCNT1;

  uint8_t i = sEvtIdx;
  uint8_t p = PORTB;
  p |=  sEvtSet[i];
  p &= ~sEvtClr[i];
  PORTB = p;

  if (++i >= sEvtCount) i = 0;
  sEvtIdx = i;
  OCR1A = sEvtDelta[i] - 1;

  if (lat > sMaxLatency) sMaxLatency = lat;
}

// --- hardware mode ---------------------------------------------------------

static void applyDutyHw(PwmChannel ch) {
  const float   duty = sDuty[ch];
  const uint8_t pin  = (ch == PWM_A) ? PIN_A : PIN_B;
  const uint8_t com  = (ch == PWM_A) ? _BV(COM1A1) : _BV(COM1B1);

  if (duty <= 0.0f) { TCCR1A &= ~com; digitalWrite(pin, LOW);  return; }
  if (duty >= 1.0f) { TCCR1A &= ~com; digitalWrite(pin, HIGH); return; }

  uint32_t counts = (uint32_t)(duty * ((uint32_t)sTop + 1) + 0.5f);
  if (counts == 0)     counts = 1;
  if (counts > sTop)   counts = sTop;

  uint8_t sreg = SREG;
  cli();
  if (ch == PWM_A) OCR1A = (uint16_t)counts;
  else             OCR1B = (uint16_t)counts;
  SREG = sreg;

  TCCR1A |= com;
}

static void startHardwareMode() {
  uint8_t sreg = SREG;
  cli();
  TIMSK1 = 0;                              // no scheduler interrupt
  // WGM13:0 = 1110 -> fast PWM, TOP = ICR1.
  TCCR1A = _BV(WGM11);
  TCCR1B = _BV(WGM13) | _BV(WGM12) | sCsBits;
  ICR1   = sTop;
  TCNT1  = 0;
  SREG = sreg;

  sSoftMode = false;
  applyDutyHw(PWM_A);
  applyDutyHw(PWM_B);
}

// --- software mode ---------------------------------------------------------

// Build the per-period edge schedule. Returns false if the outputs are static
// (no edges needed), in which case the caller holds the pins at fixed levels.
static bool buildSchedule() {
  const uint32_t period = (uint32_t)sTop + 1;

  struct Evt { uint32_t t; uint8_t set; uint8_t clr; };
  Evt e[4];
  uint8_t n = 0;

  uint8_t staticHigh = 0;   // bits held high for the whole period
  uint8_t staticLow  = 0;

  // Channel A is the phase reference: it rises at t = 0.
  if      (sDuty[PWM_A] <= 0.0f) staticLow  |= BIT_A;
  else if (sDuty[PWM_A] >= 1.0f) staticHigh |= BIT_A;
  else {
    uint32_t fall = (uint32_t)(sDuty[PWM_A] * period + 0.5f);
    if (fall == 0)      fall = 1;
    if (fall >= period) fall = period - 1;
    e[n++] = (Evt){0,    BIT_A, 0};
    e[n++] = (Evt){fall, 0,     BIT_A};
  }

  // Channel B rises at the phase offset and falls a duty-width later, wrapping
  // around the period boundary if it has to.
  if      (sDuty[PWM_B] <= 0.0f) staticLow  |= BIT_B;
  else if (sDuty[PWM_B] >= 1.0f) staticHigh |= BIT_B;
  else {
    uint32_t rise  = (uint32_t)((sPhaseDeg / 360.0f) * period + 0.5f) % period;
    uint32_t width = (uint32_t)(sDuty[PWM_B] * period + 0.5f);
    if (width == 0)      width = 1;
    if (width >= period) width = period - 1;
    uint32_t fall = (rise + width) % period;
    e[n++] = (Evt){rise, BIT_B, 0};
    e[n++] = (Evt){fall, 0,     BIT_B};
  }

  // Whatever is static this period gets applied once, here.
  uint8_t p = PORTB;
  p |=  staticHigh;
  p &= ~staticLow;
  PORTB = p;

  if (n == 0) return false;

  // Sort by time (n <= 4, so insertion sort is the right tool).
  for (uint8_t i = 1; i < n; i++) {
    Evt k = e[i];
    int8_t j = i - 1;
    while (j >= 0 && e[j].t > k.t) { e[j + 1] = e[j]; j--; }
    e[j + 1] = k;
  }

  // Merge coincident edges, then enforce a minimum spacing the ISR can service.
  // Both steps can only reduce the event count, never grow it.
  uint8_t m = 0;
  for (uint8_t i = 0; i < n; i++) {
    if (m > 0 && e[i].t == e[m - 1].t) {
      e[m - 1].set |= e[i].set;
      e[m - 1].clr |= e[i].clr;
    } else {
      e[m++] = e[i];
    }
  }
  n = m;

  uint16_t minGap = kIsrCycles / sPrescaler;
  if (minGap < 1) minGap = 1;
  sStrained = false;

  // Push events apart where they crowd. Distorts the waveform, but a missed
  // compare match would cost a whole period, which is far worse.
  for (uint8_t i = 1; i < n; i++) {
    if (e[i].t - e[i - 1].t < minGap) {
      e[i].t = e[i - 1].t + minGap;
      sStrained = true;
    }
  }
  if (n > 1 && (period - e[n - 1].t) < minGap) {
    // The wrap-around gap is too tight as well; drop the last edge's time back.
    e[n - 1].t = period - minGap;
    sStrained = true;
    if (e[n - 1].t <= e[n - 2].t) return false;   // hopeless: give up on edges
  }

  // Convert absolute times to deltas. Event 0's delta is measured from the
  // last event of the previous period, across the boundary.
  uint16_t delta[4];
  for (uint8_t i = 1; i < n; i++) delta[i] = (uint16_t)(e[i].t - e[i - 1].t);
  delta[0] = (uint16_t)(period - e[n - 1].t + e[0].t);
  if (delta[0] == 0) delta[0] = 1;

  uint8_t sreg = SREG;
  cli();
  for (uint8_t i = 0; i < n; i++) {
    sEvtDelta[i] = delta[i];
    sEvtSet[i]   = e[i].set;
    sEvtClr[i]   = e[i].clr;
  }
  sEvtCount = n;
  SREG = sreg;
  return true;
}

static void startSoftwareMode() {
  bool haveEdges = buildSchedule();

  uint8_t sreg = SREG;
  cli();
  TCCR1A = 0;                                   // compare outputs disconnected;
  TCCR1B = _BV(WGM12) | sCsBits;                // WGM = CTC, TOP = OCR1A.
  if (haveEdges) {
    sEvtIdx = 0;
    OCR1A   = sEvtDelta[0] - 1;
    TCNT1   = 0;
    TIFR1   = _BV(OCF1A);                       // clear a stale pending match
    TIMSK1  = _BV(OCIE1A);
  } else {
    TIMSK1 = 0;                                 // static levels, nothing to do
    OCR1A  = sTop;
  }
  SREG = sreg;
  sSoftMode = true;
}

// --- shared ----------------------------------------------------------------

static void applyMode() {
  if (sPhaseDeg == 0.0f) startHardwareMode();
  else                   startSoftwareMode();
}

static float configureTimer(float frequencyHz) {
  if (frequencyHz < 0.25f)      frequencyHz = 0.25f;
  if (frequencyHz > 1000000.0f) frequencyHz = 1000000.0f;

  uint16_t prescaler = kPrescalers[kNumPrescalers - 1];
  uint8_t  csBits    = kCsBits[kNumPrescalers - 1];
  uint32_t top       = 65535;

  for (uint8_t i = 0; i < kNumPrescalers; i++) {
    float candidate = (float)F_CPU / ((float)kPrescalers[i] * frequencyHz) - 1.0f;
    if (candidate <= 65535.0f) {
      prescaler = kPrescalers[i];
      csBits    = kCsBits[i];
      top       = (uint32_t)(candidate + 0.5f);
      break;
    }
  }
  if (top < 1)     top = 1;
  if (top > 65535) top = 65535;

  sTop       = (uint16_t)top;
  sPrescaler = prescaler;
  sCsBits    = csBits;
  sActualHz  = (float)F_CPU / ((float)prescaler * ((float)top + 1.0f));
  return sActualHz;
}

float pwmBegin(float frequencyHz) {
  pinMode(PIN_A, OUTPUT);
  pinMode(PIN_B, OUTPUT);
  digitalWrite(PIN_A, LOW);
  digitalWrite(PIN_B, LOW);

  TCCR1A = 0; TCCR1B = 0; TIMSK1 = 0; TCNT1 = 0;
  sDuty[PWM_A] = 0.0f;
  sDuty[PWM_B] = 0.0f;
  sPhaseDeg    = 0.0f;
  sMaxLatency  = 0;

  float hz = configureTimer(frequencyHz);
  sRunning = true;
  applyMode();
  return hz;
}

float pwmSetFrequency(float frequencyHz) {
  if (!sRunning) return pwmBegin(frequencyHz);
  float hz = configureTimer(frequencyHz);
  sMaxLatency = 0;
  applyMode();          // TOP moved, so every edge time has to be recomputed
  return hz;
}

void pwmSetDuty(PwmChannel ch, float duty) {
  if (duty < 0.0f) duty = 0.0f;
  if (duty > 1.0f) duty = 1.0f;
  sDuty[ch] = duty;
  if (!sRunning) return;
  if (sSoftMode) startSoftwareMode();
  else           applyDutyHw(ch);
}

void pwmSetDutyRaw(PwmChannel ch, uint16_t counts) {
  if (counts > sTop) counts = sTop;
  pwmSetDuty(ch, (float)counts / ((float)sTop + 1.0f));
}

void pwmSetPhase(float degrees) {
  degrees = fmod(degrees, 360.0f);
  if (degrees < 0.0f) degrees += 360.0f;
  sPhaseDeg   = degrees;
  sMaxLatency = 0;
  if (sRunning) applyMode();
}

void pwmEnd() {
  uint8_t sreg = SREG;
  cli();
  TIMSK1 = 0;
  TCCR1A = 0;
  TCCR1B = 0;
  SREG = sreg;
  sRunning  = false;
  sSoftMode = false;
  digitalWrite(PIN_A, LOW);
  digitalWrite(PIN_B, LOW);
}

uint16_t pwmTop()            { return sTop; }
float    pwmFrequency()      { return sActualHz; }
float    pwmResolutionBits() { return log((float)sTop + 1.0f) / log(2.0f); }
float    pwmPhase()          { return sPhaseDeg; }
bool     pwmSoftwareMode()   { return sSoftMode; }
bool     pwmScheduleStrained() { return sSoftMode && sStrained; }
void     pwmResetLatency()   { uint8_t s = SREG; cli(); sMaxLatency = 0; SREG = s; }

float pwmMaxLatencyUs() {
  uint8_t s = SREG; cli();
  uint16_t lat = sMaxLatency;
  SREG = s;
  return (float)lat * (float)sPrescaler / (F_CPU / 1000000.0f);
}

// ===========================================================================
//  Sketch - serial command interface
// ===========================================================================

static const unsigned long kBaud       = 115200;
static const float         kStartHz    = 1000.0f;
static const uint8_t       kPotPin     = A0;
static const uint16_t      kPotDeadband = 4;  // ADC counts of hysteresis

static bool     potMode     = false;
static uint16_t lastPotRaw  = 0;
static char     line[32];
static uint8_t  lineLen     = 0;

// ---------------------------------------------------------------------------

// Duty is shadowed locally so status reports what was asked for, not what the
// compare register rounded to.
static float shadowDuty[2] = {0.0f, 0.0f};

static float dutyPercent(PwmChannel ch) { return shadowDuty[ch] * 100.0f; }

static void setDutyPercent(PwmChannel ch, float percent) {
  if (percent < 0.0f)   percent = 0.0f;
  if (percent > 100.0f) percent = 100.0f;
  shadowDuty[ch] = percent / 100.0f;
  pwmSetDuty(ch, shadowDuty[ch]);
}

static void printStatus() {
  Serial.println(F("--- PWM status ---"));
  Serial.print(F("  frequency : ")); Serial.print(pwmFrequency(), 3); Serial.println(F(" Hz"));
  Serial.print(F("  TOP       : ")); Serial.print(pwmTop());
  Serial.print(F("  ("));            Serial.print(pwmResolutionBits(), 2);
  Serial.println(F(" bits of duty resolution)"));
  Serial.print(F("  A (pin 9) : ")); Serial.print(dutyPercent(PWM_A), 2); Serial.println(F(" %"));
  Serial.print(F("  B (pin 10): ")); Serial.print(dutyPercent(PWM_B), 2); Serial.println(F(" %"));
  Serial.print(F("  phase B-A : ")); Serial.print(pwmPhase(), 1); Serial.println(F(" deg"));
  Serial.print(F("  mode      : "));
  Serial.println(pwmSoftwareMode() ? F("software (ISR scheduler)") : F("hardware (compare units)"));
  if (pwmSoftwareMode()) {
    Serial.print(F("  ISR jitter: worst ")); Serial.print(pwmMaxLatencyUs(), 2);
    Serial.println(F(" us  <- real phase/duty error"));
    if (pwmScheduleStrained())
      Serial.println(F("  WARNING   : edges too close to service - output is being distorted"));
  }
  Serial.print(F("  A0 control: ")); Serial.println(potMode ? F("on") : F("off"));
}

static void printHelp() {
  Serial.println(F("f <hz>      frequency, 0.25 .. 1000000"));
  Serial.println(F("a <pct>     duty on pin 9"));
  Serial.println(F("b <pct>     duty on pin 10"));
  Serial.println(F("ph <deg>    phase of pin 10 behind pin 9, 0 .. 360"));
  Serial.println(F("pot on|off  A0 potentiometer drives channel A"));
  Serial.println(F("sweep       0 -> 100 -> 0 % ramp on channel A"));
  Serial.println(F("s           status"));
}

static void doSweep() {
  Serial.println(F("sweeping channel A..."));
  const bool wasPot = potMode;
  potMode = false;
  for (int p = 0; p <= 100; p++) { setDutyPercent(PWM_A, p); delay(15); }
  for (int p = 100; p >= 0; p--) { setDutyPercent(PWM_A, p); delay(15); }
  potMode = wasPot;
  Serial.println(F("done"));
}

static void handleLine(char *s) {
  while (*s == ' ') s++;
  if (*s == '\0') return;

  const char cmd = *s;
  char *arg = s + 1;
  while (*arg == ' ') arg++;

  switch (cmd) {
    case 'f': {
      float hz = atof(arg);
      float actual = pwmSetFrequency(hz);
      Serial.print(F("frequency -> ")); Serial.print(actual, 3);
      Serial.print(F(" Hz, ")); Serial.print(pwmResolutionBits(), 2);
      Serial.println(F(" bits"));
      break;
    }
    case 'a':
      setDutyPercent(PWM_A, atof(arg));
      Serial.print(F("A -> ")); Serial.print(dutyPercent(PWM_A), 2); Serial.println(F(" %"));
      break;
    case 'b':
      setDutyPercent(PWM_B, atof(arg));
      Serial.print(F("B -> ")); Serial.print(dutyPercent(PWM_B), 2); Serial.println(F(" %"));
      break;
    case 'p':
      if (s[1] == 'h') {                      // "ph <deg>"
        char *deg = s + 2;
        while (*deg == ' ') deg++;
        pwmSetPhase(atof(deg));
        Serial.print(F("phase -> ")); Serial.print(pwmPhase(), 1);
        Serial.print(F(" deg, "));
        Serial.println(pwmSoftwareMode() ? F("software mode") : F("hardware mode"));
        if (pwmScheduleStrained())
          Serial.println(F("WARNING: edges too close to service at this frequency"));
        break;
      }
      // Match against the whole line: `arg` starts mid-word here ("pot off"
      // leaves arg pointing at "ot off"), so a prefix compare would misread it.
      potMode = (strstr(s, "off") == NULL);   // "pot" alone turns it on
      Serial.print(F("A0 control ")); Serial.println(potMode ? F("on") : F("off"));
      break;
    case 'S':
    case 's':
      if (s[1] == 'w') doSweep();   // "sweep"
      else             printStatus();
      break;
    case '?':
    case 'h':
      printHelp();
      break;
    default:
      Serial.println(F("? unknown command - type ? for the list"));
  }
}

// ---------------------------------------------------------------------------

void setup() {
  Serial.begin(kBaud);
  while (!Serial) { ; }   // needed on native-USB boards, harmless on a Uno

  float hz = pwmBegin(kStartHz);
  setDutyPercent(PWM_A, 50.0f);
  setDutyPercent(PWM_B, 25.0f);

  Serial.println(F("\nPWM generator ready - pin 9 = A, pin 10 = B"));
  Serial.print(F("starting at ")); Serial.print(hz, 2); Serial.println(F(" Hz"));
  printHelp();
  lastPotRaw = analogRead(kPotPin);
}

void loop() {
  // Serial command parsing, one character at a time so loop() never blocks.
  while (Serial.available()) {
    char c = Serial.read();
    if (c == '\r') continue;
    if (c == '\n') {
      line[lineLen] = '\0';
      handleLine(line);
      lineLen = 0;
    } else if (lineLen < sizeof(line) - 1) {
      line[lineLen++] = c;
    }
  }

  if (potMode) {
    uint16_t raw = analogRead(kPotPin);
    // Deadband keeps ADC noise from rewriting OCR1A on every pass.
    if ((raw > lastPotRaw ? raw - lastPotRaw : lastPotRaw - raw) >= kPotDeadband) {
      lastPotRaw = raw;
      setDutyPercent(PWM_A, raw * (100.0f / 1023.0f));
    }
  }
}

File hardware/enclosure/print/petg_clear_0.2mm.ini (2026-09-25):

# PrusaSlicer settings for the transparent PETG enclosure (0.4 mm nozzle, 0.2 mm layers).
# Load in PrusaSlicer: File > Import > Import Config, or on the command line with --load.
# Printer part is generic (250 x 210 bed); pick your own printer profile and keep the print/filament values.
bed_shape = 0x0,250x0,250x210,0x210
max_print_height = 210
nozzle_diameter = 0.4
gcode_flavor = marlin2
use_relative_e_distances = 1
layer_gcode = G92 E0
layer_height = 0.2
first_layer_height = 0.2
perimeters = 6
top_solid_layers = 12
bottom_solid_layers = 12
fill_density = 100%
fill_pattern = rectilinear
top_fill_pattern = monotonic
bottom_fill_pattern = monotonic
solid_infill_every_layers = 0
infill_anchor = 0
fill_angle = 45
external_perimeters_first = 0
extrusion_multiplier = 1.03
extrusion_width = 0.45
perimeter_extrusion_width = 0.45
external_perimeter_extrusion_width = 0.45
infill_extrusion_width = 0.45
solid_infill_extrusion_width = 0.45
top_infill_extrusion_width = 0.42
seam_position = rear
support_material = 0
ironing = 0
thin_walls = 0
# slow, hot and fan-light = fewer trapped bubbles and better layer fusion = clearer part
first_layer_speed = 15
external_perimeter_speed = 15
perimeter_speed = 25
small_perimeter_speed = 15
infill_speed = 30
solid_infill_speed = 30
top_solid_infill_speed = 20
bridge_speed = 20
gap_fill_speed = 20
travel_speed = 150
retract_length = 0.8
retract_speed = 35
# PETG (recycled rPETG: same settings; dry it first, 65 C / 4 h)
filament_type = PETG
filament_diameter = 1.75
filament_density = 1.27
filament_cost = 25
temperature = 250
first_layer_temperature = 245
bed_temperature = 80
first_layer_bed_temperature = 80
cooling = 1
min_fan_speed = 15
max_fan_speed = 30
bridge_fan_speed = 50
disable_fan_first_layers = 3
fan_below_layer_time = 20
slowdown_below_layer_time = 15

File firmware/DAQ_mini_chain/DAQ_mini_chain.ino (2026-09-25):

// DAQ "mini system" on a breadboard: DAC -> Arduino -> PWM -> ADC
//
// !! BREADBOARD WIRING ONLY.  Do not run this on the DAQ shield (hardware/mie1001_daq_simple):
// !! on the shield, ADS1115 A1 is PRE_OUT (the Faraday-cup preamp output), A2 is the QPS_OUT
// !! read-back (JP1) and A3 is VREF, and nothing connects D9 or the UNO's A0.  For the shield use
// !! DAQ_loopback_test (bring-up) or DAQ_shield_scan (measurements).
//
//   MCP4725 DAC sets a voltage (the "command")
//     -> UNO A0 reads it (the UNO's own ADC)
//     -> UNO makes a PWM on D9 with the same duty (V / 5 V)
//     -> a 1k + 100 nF (104) RC filter smooths the PWM back into a DC voltage
//     -> ADS1115 A0 measures it
//   If everything works, what the ADS1115 reads equals what the DAC was set to.
//
// Breadboard wiring (UNO + Adafruit ADS1115 + SparkFun MCP4725):
//   UNO 5V   -> ADS1115 VDD, MCP4725 VCC        UNO GND -> ADS1115 GND, MCP4725 GND
//   UNO SDA  -> ADS1115 SDA, MCP4725 SDA        UNO SCL -> ADS1115 SCL, MCP4725 SCL
//   ADS1115 ADDR -> GND (0x48)                  MCP4725 address jumper at 0x60
//   MCP4725 OUT -> UNO A0
//   UNO D9 -> 1k -> ADS1115 A0,   ADS1115 A0 -> 100 nF -> GND
//   optional: MCP4725 OUT -> ADS1115 A1 so the ADS1115 also sees the DAC directly
//
// Libraries: Adafruit ADS1X15, Adafruit MCP4725.  Serial Monitor: 115200 baud, Newline.
// Commands: a voltage (e.g. 2.5) holds the DAC there, 's' runs the sweep again.

#include <Wire.h>
#include <Adafruit_ADS1X15.h>
#include <Adafruit_MCP4725.h>

Adafruit_ADS1115 ads;
Adafruit_MCP4725 dac;

const uint8_t DAC_ADDR = 0x60;       // NOT the library default (0x62)
const uint8_t CMD_PIN  = A0;         // UNO A0 (not the ADS1115's A0)
const uint8_t PWM_PIN  = 9;          // Timer1 OC1A
const bool    DIRECT_ON_A1 = true;   // set false if MCP4725 OUT is not also wired to ADS1115 A1

// 10-bit PWM on D9 at 15.6 kHz (Timer1, fast PWM, TOP = ICR1 = 1023).
// The 1k + 100 nF filter (1.6 kHz corner) leaves some ripple; the ADS1115 averages each conversion
// over 7.8 ms (~120 PWM periods), so it reads the average voltage.
void pwmBegin() {
  pinMode(PWM_PIN, OUTPUT);
  TCCR1A = _BV(COM1A1) | _BV(WGM11);
  TCCR1B = _BV(WGM13) | _BV(WGM12) | _BV(CS10);
  ICR1 = 1023;
  OCR1A = 0;
}

// The "controller": read the command on UNO A0, copy it to the PWM duty.
// analogRead and the PWM both use the 5 V rail as reference, so its exact value cancels out.
uint16_t cmdCounts = 0;
void follow() {
  long sum = 0;
  for (uint8_t i = 0; i < 8; i++) sum += analogRead(CMD_PIN);
  cmdCounts = sum / 8;
  OCR1A = cmdCounts;
}

float adsVolts(uint8_t ch) {
  ads.readADC_SingleEnded(ch);       // discard one conversion after a channel change
  long sum = 0;
  for (uint8_t i = 0; i < 4; i++) sum += ads.readADC_SingleEnded(ch);
  return ads.computeVolts(sum / 4);
}

void measure(uint16_t code) {
  dac.setVoltage(code, false);
  delay(5);
  follow();
  delay(10);                         // filter settles in ~2.5 ms
  float vOut = adsVolts(0);
  Serial.print(code); Serial.print('\t');
  Serial.print(cmdCounts); Serial.print('\t');
  Serial.print(cmdCounts / 10.23, 1); Serial.print("%\t");
  if (DIRECT_ON_A1) {
    float vIn = adsVolts(1);
    Serial.print(vIn, 3); Serial.print('\t');
    Serial.print(vOut, 3); Serial.print('\t');
    Serial.println((vOut - vIn) * 1000, 0);
  } else {
    Serial.println(vOut, 3);
  }
}

void header() {
  Serial.print(F("\nDAC\tUNO A0\tduty\t"));
  Serial.println(DIRECT_ON_A1 ? F("V_dac\tV_pwm\terr mV") : F("V_pwm"));
}

void sweep() {
  header();
  for (uint16_t code = 0; code <= 4096; code += 512) measure(code > 4095 ? 4095 : code);
}


void setup() {
  Serial.begin(115200);
  Serial.println(F("\n=== DAQ mini chain: DAC -> UNO A0 -> PWM D9 -> ADS1115 ==="));
  Wire.begin();
  Wire.setWireTimeout(25000, true);
  if (!ads.begin(0x48)) { Serial.println(F("ADS1115 not found at 0x48")); while (1); }
  if (!dac.begin(DAC_ADDR)) { Serial.println(F("MCP4725 not found at 0x60")); while (1); }
  ads.setGain(GAIN_TWOTHIRDS);       // +/-6.144 V range
  ads.setDataRate(RATE_ADS1115_128SPS);
  pwmBegin();
  sweep();
  Serial.println(F("\nType a voltage (e.g. 2.5) to hold the DAC there, or 's' to sweep."));
}

void loop() {
  follow();                          // the control loop runs all the time

  if (Serial.available()) {
    String line = Serial.readStringUntil('\n');
    line.trim();
    if (line == "s" || line == "S") { sweep(); return; }
    if (line.length()) {
      float v = line.toFloat();
      if (v < 0 || v > 5.0) { Serial.println(F("0 to 5 V")); return; }
      uint16_t code = min(4095, (int)(v / 5.0 * 4096 + 0.5));  // assumes a 5 V rail; the chain doesn't care
      header();
      measure(code);
    }
  }
}

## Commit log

2026-09-24 MIE1001 Team 5 DAQ: firmware sketches and both shield designs
    Arduino test sketches (ADS1115, MCP4725, loopback, breadboard chain, PWM tool),
    the simple breakout shield rev D with the Faraday-cup preamp, and the full
    shield rev E. Boards are generated by Python; build.sh runs ERC/DRC/guard checks.
    [BOM.csv, jlcpcb_bom.csv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]
2026-09-25 Shield rev E, Digi-Key ordering, shield firmware, self-test data, enclosure
    - Simple shield rev E: fixes from an embedded-systems design review (guard ring
    closed under the LMP7721 and free of solder mask, 100k/100k VREF divider, A4/A5
    wired to SDA/SCL, JP1 mass-command read-back on ADS A2, flood-fill guard check
    that fails on rev D). Parts re-verified at Digi-Key; fab/digikey_bom.csv added,
    README covers ordering the bare PCB via DigiKey PCB Builder and hand-soldering.
    - firmware/DAQ_shield_scan: preamp current (A1-A3), zero, settled mass scan with
    50 Hz window averaging, A2 command read-back, trigger on D8, self-check.
    - Team sketches: ioannis_DAC_3V (now corrects for the real 5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
    [BOM.csv, daq_base.stl, daq_enclosure.scad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]
2026-09-25 Add labelled Serial Plotter simulation of MCP4725_sine_scope and plotter-style view of the real self-test
    [sim_sine_scope.csv]
2026-09-25 Enclosure: plain box for UNO + shield by default, no Faraday-cup adapter opening
    [daq_enclosure.scad, daq_lid.stl]
2026-09-25 Shield rev E: neutral silkscreen text (possum kept), Digi-Key ordering files
    [mie1001_daq_simple-B_Cu.gbl, mie1001_daq_simple-B_Mask.gbs, mie1001_daq_simple-B_Silkscreen.gbo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]
2026-09-25 Add the Wokwi simulation (scan sketch, wiring, custom ADS1115/MCP4725/quad chips)
